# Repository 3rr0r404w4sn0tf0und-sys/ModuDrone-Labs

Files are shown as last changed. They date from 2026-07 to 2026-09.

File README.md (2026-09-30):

# ModuDrone Labs v1

An open-source, heavy-lift agricultural octocopter designed to challenge closed, proprietary drone ecosystems. ModuDrone Labs v1 is a student-led, 4-year engineering initiative focused on building a modular, repairable, and high-performance industrial flight platform using off-the-shelf hardware and custom fabrication.

## 🚀 Quick Links
* **CAD**  :  [Onshape CAD](https://cad.onshape.com/documents/e87d46874a385fbec040f01c/w/3f5500552e76a844099c1e4a/e/fdc0c3d3f0b3d21b94bce90c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)
* **ODOO** :  [https://modudrone-labs.odoo.com/](https://modudrone-labs.odoo.com/) 
---

## 📐 Platform Specifications

* **Frame Configuration**: Industrial Co-Axial Octocopter (4-Arm design with 3K Carbon Fiber tubes)
* **Propulsion Stack**: MAD Components M7C15 IPE motors spinning 27.2*8.9" MAD Fluxer Props
* **Communications Protocol**: Integrated DroneCAN architecture for robust electronic reliability
* **Primary Flight Controller**: Pixhawk 6x with triple redundancy and mroe ports for expansion
* **Companion Intelligence**: Jetson Orin Nano Developer Kit for localized AI perception and processing
* **Sensor Payload**: YDLIDAR G4, TFmini-Plus altimeter, and SIYI ZR30 Gimbal Camera
* **RTK GPS**: H-RTK mosaic-H (Dual Antenna Heading)
* **Power Plant**: 2 Foxtech 12S 36000mAh Batterys running through a MAUCH PDB

---

## 🛠 Project Lifecycle & Current Status

This is a long-term **4-year project** focused on absolute engineering transparency. 

* **Phase 1: Conceptual Architecture & CAD Modeling** ------------------------------------------ 🔵 *[COMPLETED]*
  * Finalizing the aerodynamic central fuselage hull shell within Onshape.
  * Structural layout optimization for the 8-arm carbon fiber chassis leverage points.




* **Phase 2: R&D Prototyping & Design** -------------------------------------------------------- 🟢 *[CURRENT PHASE]*
  * Wind Tunnel Testing
  * AIRsim testing
  * Extra Reinforcements and CAD check period.
* **Phase 3: Funding** ------------------------------------------------------------------------- 🟡
  * Grant proposals and applications
* **Phase 4: Flight Integration & Testing** ---------------------------------------------------- 🔴
  * 3d print the frame and build it.
  * Core autopilot parameter tuning and testing sensory loop feedback (LiDAR / Gimbal).
* **Phase 5: Part 47, 44807, manual, and legal draft - Funding Period 2** ---------------------- 🔴
  * Hire Lawyer to write legal contracts, and forms to acquire the part 47 heavy lift exemption.
  * Write the User Manual
  * Make 44807 template
  * RTL testing, and Failsafe Testing.
* **Phase 6: Open Commercialization** ---------------------------------------------------------- 🔴
  * Launching open-source kit architectures for independent distribution.

---

## 📜 Licensing & The Anti-Proprietary Shield

We believe hardware ecosystems should be accessible and owned by the community, not locked down by restrictive corporations. To guarantee this project remains permanently open, it is protected under a strict copyleft shield:

* **Software & Configurations**: This repository's code, scripts, and flight configuration files are initially licensed under the **GNU Affero General Public License v3 (AGPLv3)**. 
* **Hardware & Geometry**: *All physical CAD models, STEP files, and frame geometries are governed by the [CERN Open Hardware Licence v2 - Strongly Reciprocal (CERN-OHL-S-2.0)](./CAD/HARDWARE_LICENSE.md)*

**The Copyleft Guarantee**: Anyone is legally allowed to modify, adapt, or build upon this architecture. However, any derivative modifications or improvements **must be published openly under these exact same terms**. If you optimize our layout, your improvements must legally remain free for the public—and us—to utilize.
- 💻 **Software & Configurations:** Licensed under [GNU AGPLv3](LICENSE) — `SPDX-License-Identifier: AGPL-3.0-only`
- 🔩 **Hardware & Geometry:** Licensed under [CERN-OHL-S-2.0](CAD/HARDWARE_LICENSE.md) — `SPDX-License-Identifier: CERN-OHL-S-2.0`

---

## 👥 Core Engineering Team
Developed with passion by a student-led engineering collective. 
* **Contact**: ModuDroneTeam@hotmail.com

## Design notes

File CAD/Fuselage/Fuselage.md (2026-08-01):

# 🛩️ **Fuselage CAD Directory**
This folder contains all CAD models, assemblies, and reference geometry for the **ModuDrone main fuselage**.  
It serves as the central workspace for the structural body that houses the drone’s internal systems.

---

## 📦 **What Lives Here**
- Full fuselage **solid models**  



---

## 🧱 **Design Intent**
The fuselage is engineered to:
- Provide a rigid central structure for the Co-Axial layout  
- Support high‑torque MAD motor loads through reinforced clamp nodes  
- Maximize internal usable volume while minimizing mass  
- Maintain clean airflow paths for cooling and sensor visibility  
- Serve as the anchor for all modular subsystems in the ModuDrone platform

---

## 🔄 **Update Workflow**
All fuselage changes should follow the standard ModuDrone workflow:
1. Edit or add CAD in Onshape  
2. Export STEP files  
3. Commit to this directory with a clear message  
4. Add notes to `Updates.md` if the change affects assembly geometry or subsystem integration

---

## 📘 **Notes**
This folder is actively evolving as the fuselage transitions from a visual prototype to a weight‑optimized flight‑ready structure.  
Expect frequent updates as internal hollowing, mounting revisions, and structural optimizations progress.

V2 is missing as it was just pure sketches.

---

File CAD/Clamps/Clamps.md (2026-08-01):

# 🔩 **Clamp CAD Directory**
This folder contains all CAD models, assemblies, and reference geometry for the **ModuDrone clamping systems**, including both **motor‑mount clamps** and **arm clamps**.  
These components mechanically secure the propulsion system and structural arms to the fuselage.

---

## 🧱 **What’s Inside**
### **Motor‑Mount Clamps**
- 30 mm carbon‑fiber tube clamp bodies  
- PA612‑CF printable variants  
- M6 heat‑set insert bosses (7–8 mm reinforced)  
- Through‑pin channel geometry for torque‑locking  
- Mounting interfaces for MAD HAVOC motor plates

(With Simplified Motors)

---

## 🛠️ **Design Intent**
The clamp subsystem is engineered to:
- Provide rigid, slip‑free attachment of arms and motor tubes  
- Withstand high‑torque loads from large‑format MAD motors  
- Maintain precise thrust‑vector alignment across the V‑Octo layout  
- Support PA612‑CF manufacturing constraints (wall thickness, boss geometry, print orientation)  
- Allow modular replacement and rapid iteration during prototyping

---

## 🔄 **Update Workflow**
1. Modify or create clamp geometry in Onshape  
2. Export STEP files  
3. Commit changes with clear version notes  
4. Add relevant updates to `Updates.md` if clamp geometry affects fuselage, motor spacing, or assembly alignment

---

## 📘 **Notes**
This directory evolves alongside the fuselage and propulsion system.  
Expect frequent updates as clamp strength, weight, and manufacturability are optimized for PA612‑CF printing and high‑thrust MAD motor operation.

---

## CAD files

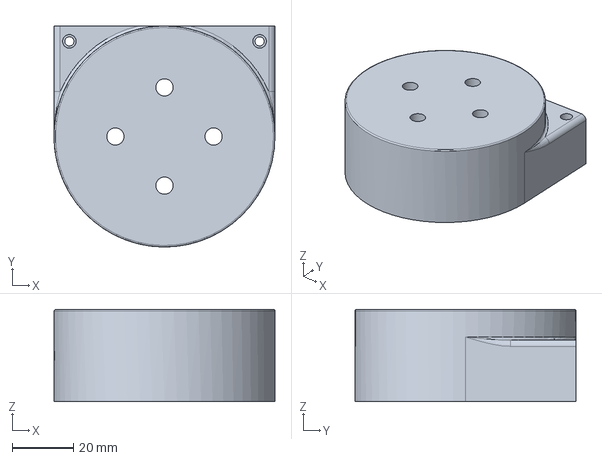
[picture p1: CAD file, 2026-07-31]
CAD/Clamps/Main motor mount V4-Top.step
72.0 x 72.0 x 30.0 mm

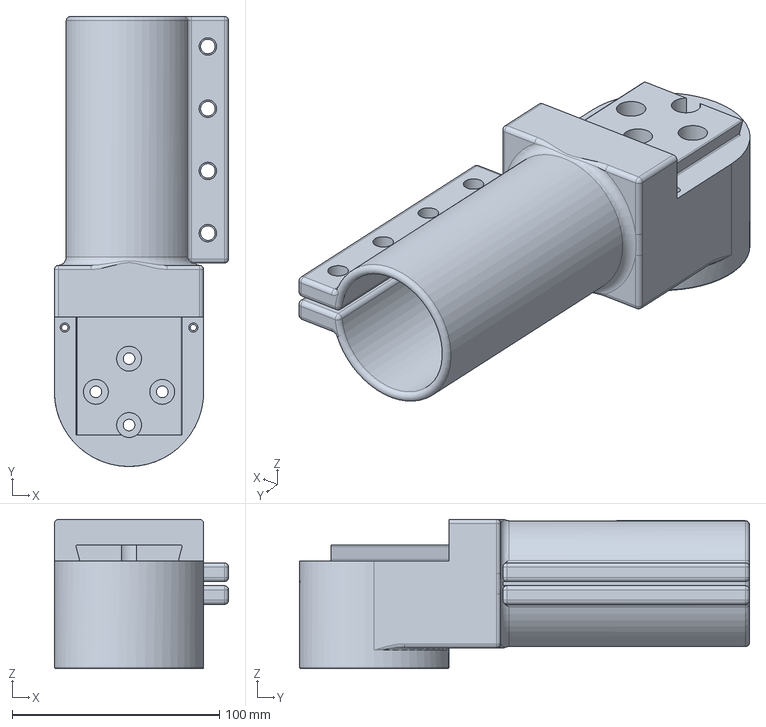
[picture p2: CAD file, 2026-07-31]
CAD/Clamps/Motor/Main motor mount V4-Bottom.step
84.0 x 217.0 x 72.0 mm

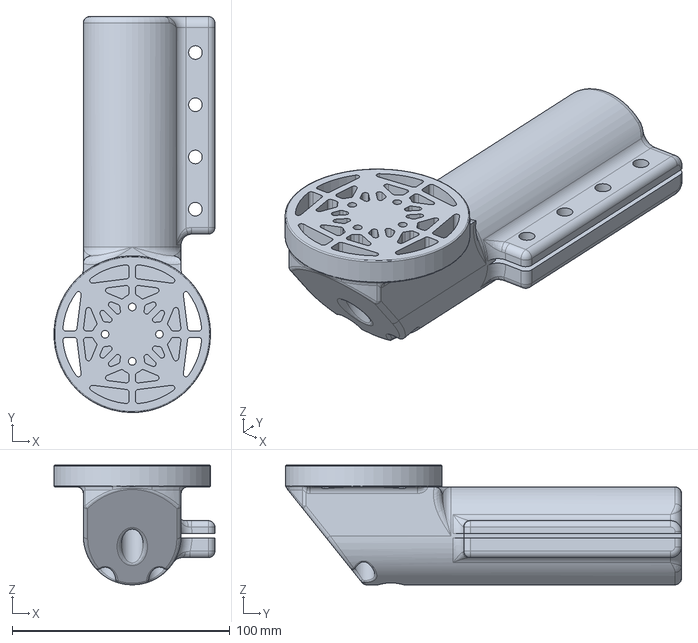
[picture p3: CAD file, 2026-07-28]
CAD/Clamps/Main motor mount V2.step
73.9 x 182.0 x 55.0 mm

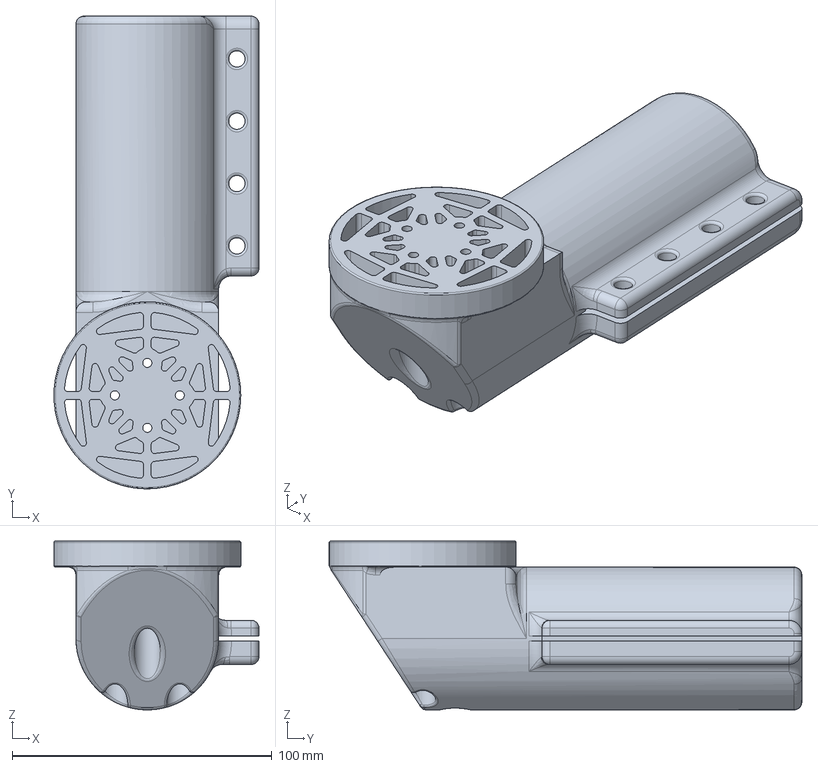
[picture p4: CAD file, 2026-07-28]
CAD/Clamps/Motor/Main motor mount V3.step
78.9 x 182.0 x 65.0 mm

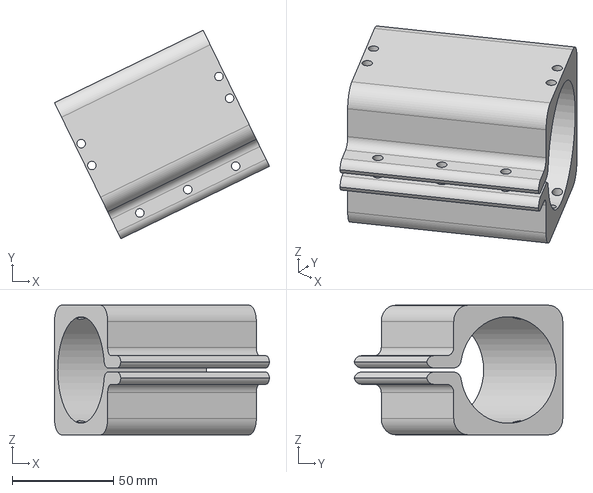
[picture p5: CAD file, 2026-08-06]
CAD/Clamps/ESC/Fuselage Design v6 - ESC Clamp Back.step
106.3 x 103.2 x 64.1 mm

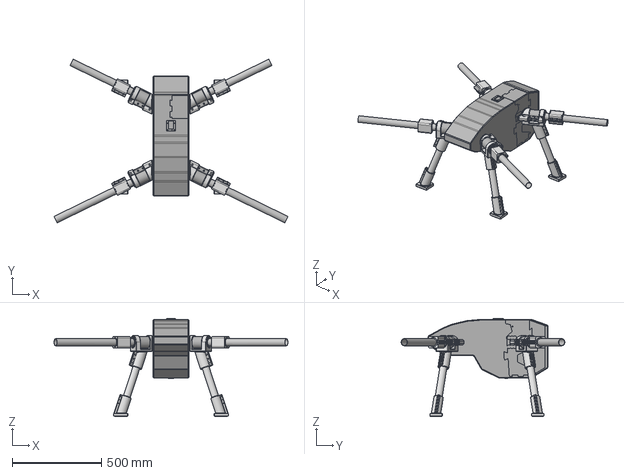
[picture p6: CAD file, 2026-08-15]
CAD/Fuselage/Fuselage Design v7 - Static.step
1312.2 x 918.1 x 550.8 mm

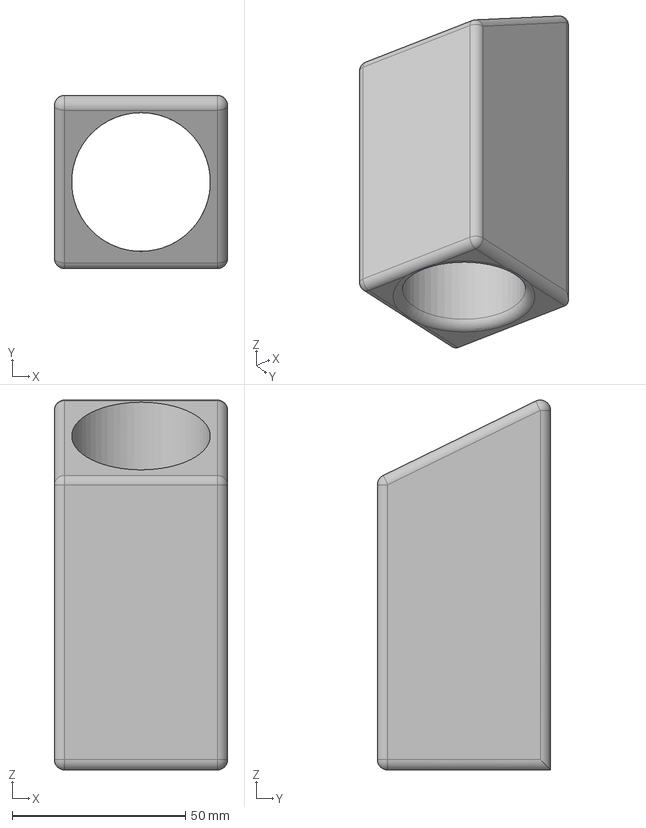
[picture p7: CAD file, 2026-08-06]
CAD/Guides/Arm Cut Guide.step
50.0 x 50.0 x 106.7 mm

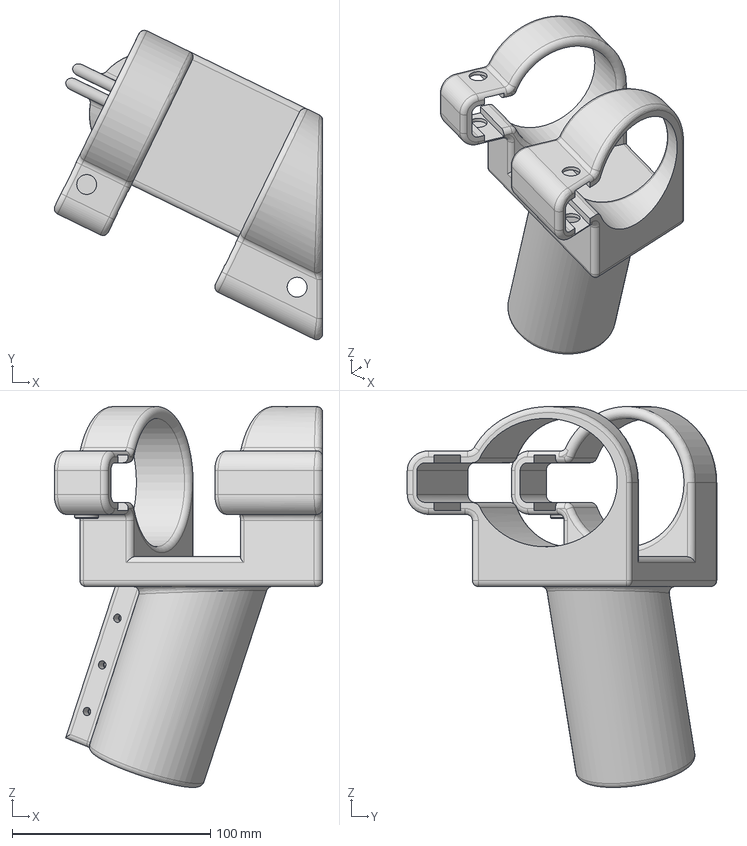
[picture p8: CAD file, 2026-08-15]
CAD/Landing Gear/Clamps/Landing Gear Mount Back Right.step
135.3 x 156.0 x 192.0 mm

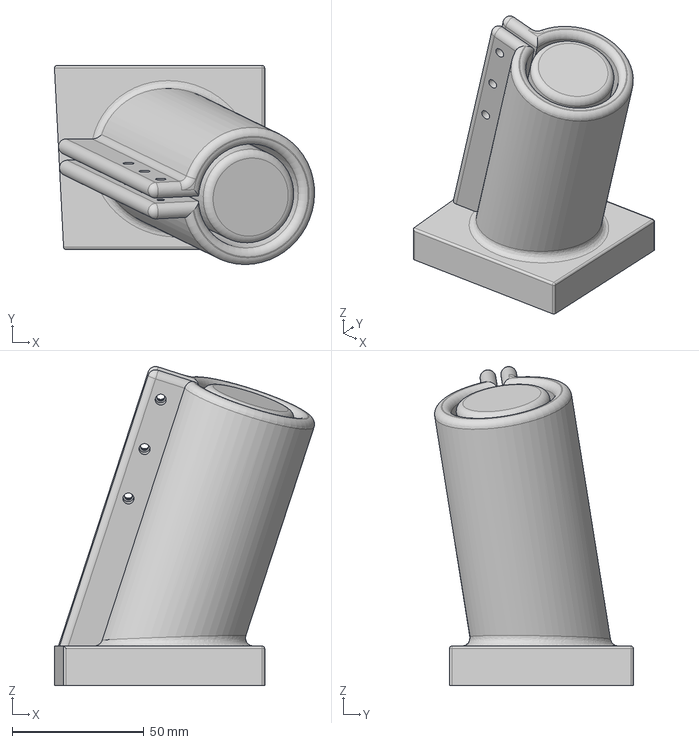
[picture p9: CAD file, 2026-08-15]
CAD/Landing Gear/Feet/Foot 4.step
98.9 x 75.7 x 121.3 mm

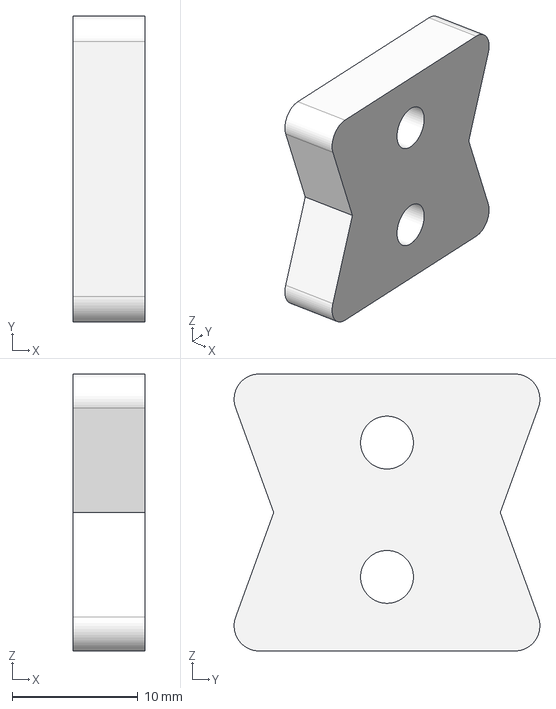
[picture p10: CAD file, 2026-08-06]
CAD/Printed Locking Plates/Printed Back Locking Plate 2x.step
5.70 x 24.3 x 22.0 mm

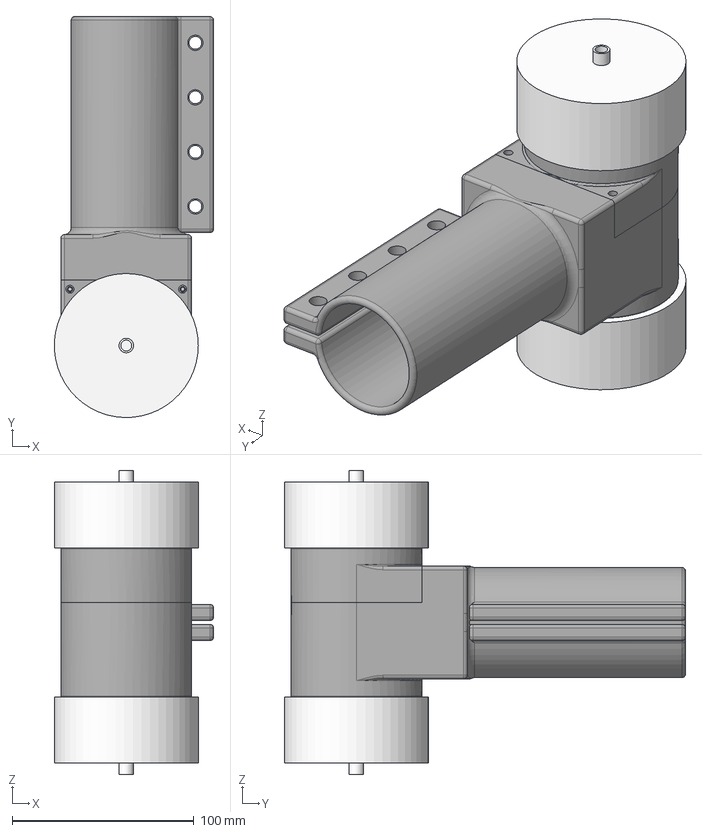
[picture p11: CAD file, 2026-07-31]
CAD/Clamps/Motor/Motor Mount Static.step
87.5 x 220.6 x 167.4 mm
M4 10mm Button Head v1:1__Body1 x 8
Clamp V4 Top
Simp Model x 2
Clamp V4 Bottom
M3 30mm Button Head v1:1__Body1 x 2

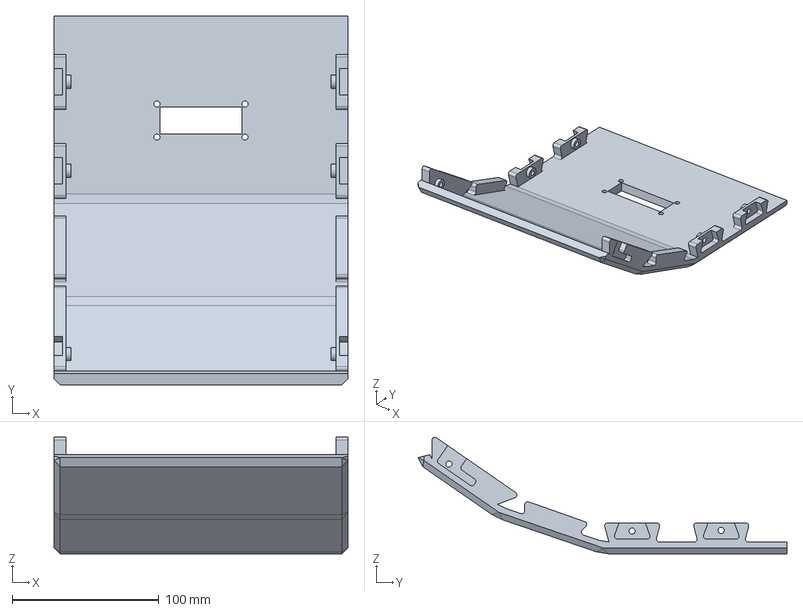
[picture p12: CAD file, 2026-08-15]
CAD/Fuselage/Fuselage Design v7 - Front Bottom.step
200.0 x 251.4 x 79.4 mm

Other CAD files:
CAD/Clamps/ESC/Fuselage Design v6 - ESC Clamp Front.step
CAD/Landing Gear/Clamps/Landing Gear Mount Front Left.step
CAD/Landing Gear/Feet/Foot 3.step
CAD/Printed Locking Plates/Printed Middle Locking Plate 2x.step
CAD/Clamps/Archive/Motor mount V1.step
CAD/Clamps/Main motor mount V1.step
CAD/Fuselage/Archive/Fuselage Design v1.step
CAD/Fuselage/Archive/Fuselage Design v3.step
CAD/Fuselage/Archive/Fuselage Design v4-Arms.step
CAD/Fuselage/Archive/Fuselage Design v4-No Arms.step
CAD/Fuselage/Archive/Fuselage Design v6 - Back Bottom.step
CAD/Fuselage/Archive/Fuselage Design v6 - Back Top.step
CAD/Fuselage/Archive/Fuselage Design v6 - Front Bottom.step
CAD/Fuselage/Archive/Fuselage Design v6 - Front L.step
CAD/Fuselage/Archive/Fuselage Design v6 - Front R.step
CAD/Fuselage/Archive/Fuselage Design v6 - Middle Bottom.step
CAD/Fuselage/Archive/Fuselage Design v6 - Middle Left 1.step
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

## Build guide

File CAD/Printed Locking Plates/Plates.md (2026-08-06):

# Printed Locking Plates
This folder contains all 3D‑printed locking plates used in the ModuDrone v1 fuselage and module system.

These plates are specifically for **tight or constrained areas** where standard T‑brackets, steel plates, or larger structural connectors cannot fit.  
They provide lightweight reinforcement, alignment, and clamping for small interfaces throughout the drone.



## Included in this folder
- Small locking plates for rib interfaces  
- Clamp plates for sockets and mounts  
- Thin reinforcement plates for narrow structural gaps  
- Cover plates for wiring channels or tight access points  
- Any plate designed to “lock” two parts together where a T‑bracket is too large

## Notes
- All plates in this folder are designed for **3D printing only**  
- Typical print settings: 3 walls, 25–40% gyroid, CF‑Nylon  
- Fasteners vary (M3–M6) depending on the plate’s location  
- These plates are used throughout the fuselage, front module, and rear module

## Purpose of this folder
To keep all **small-format structural locking plates** organized in one place, separate from other parts

This ensures the CAD directory stays clean and modular as the V6 fuselage expands.

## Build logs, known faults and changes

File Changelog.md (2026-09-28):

## 🛠️ Engineering Update — FC, GPS, and controllers change.
**📅 2026‑09‑28 • 06:26 EDT**

### Summary of Major Revisions
- **Fuselage:** V6 Rev6 → **V7**
- **Motor Clamp:** V4 (unchanged)  
- **Arm Clamp:** V1 (unchanged)  
- **ESC Clamp:** V1 (unchanged)  
---

### 🔧 Major Milestones
- New FC change and RTK GPS change
- Battery bay change
- Controller change
---

### 📐 Structural Improvements
- Battery bay changed back and moved to the center for better COG/COM
---
### Changes
- Controllers changed from T16000m HOSAS to HOSAS Gladiator NXT evo controllers
- Faster lower latency in theory controls
- Direct from Pi 02w to HM30 Ground Unit
---
### 📦 BOM Updates
- Major FC and GPS change
- Changed FC from Cube Orange to Pixhawk 6x
- Changed GPS from cheap m10 GPS to H-RTK Mosaic-H dual antenna GPS

---

### 🧩 Next Steps
- AIR sim Testing.     

---
## 🛠️ Engineering Update — Fuselage **V7 Release**
**📅 2026‑08‑18 • 10:52 EDT**

### Summary of Major Revisions
- **Fuselage:** V6 Rev6 → **V7**
- **Motor Clamp:** V4 (unchanged)  
- **Arm Clamp:** V1 (unchanged)  
- **ESC Clamp:** V1 (unchanged)  
---

### 🔧 Major Milestones
- Entered **Fuselage V7**, a refinement‑focused update aimed at precision, CG stability, and control‑system responsiveness.  
- Completed a **full battery bay redesign** to achieve perfectly centered mass alignment:  
  - CG offset now **<5 mm** on all lateral axes(Y axis should balance out once wiring is added)  
  - Balanced cable routing to maintain equal electrical path lengths  
- Began **experimental low‑latency control system Researching** using:  
  - **Gladiator NXT EVO sticks**  
  - **Direct UART injection** into the flight controller  

---
<table>
<tr>
<td></td>
<td></td>
<td></td>
</tr>
</table>

### 📐 Structural Improvements
- Battery bay geometry updated for centered dual‑pack seating:  
  - Re‑profiled lower fuselage curvature  
  - Adjusted rib cutouts for symmetric load distribution  
  - Cleaned internal routing channels for parallel 12S pack leads  
- No major changes to landing gear, fuselage ribs, or carbon‑rod bracing beyond minor alignment tweaks required by the new battery bay.

---

### 📦 BOM Updates
- No major BOM changes for V7.  
- Battery‑related connectors and cable lengths remain identical to V6 Rev6.

---

### 🧩 Next Steps
- Gazebo Testing.  
- Continue latency‑reduction researching.   

---
## 🛠️ Engineering Update — Landing Gear & Capacity Expansion  
**📅 2026‑08‑10 • 00:55 EDT**
### Summary of Major Revisions
- **Fuselage:** V6 → **V6 Rev6**  
- **Motor Clamp:** V4 (unchanged)  
- **Arm Clamp:** V1 (unchanged)  
- **ESC Clamp:** V1 (unchanged)  
- **New Additions:**
    - Landing Gear System V1(Initial Launch)
    - Expanded Dual‑Battery Bay (72 Ah 12S)
---
<details>
<summary>📷 image</summary>


</details>

### 🔧 Major Milestones
- Entered **Fuselage V6 Rev6**, marking the shift toward flight‑ready geometry and subsystem integration.  
- Added a full **landing gear assembly** designed for agricultural UAV operations:  
  - Wide‑stance geometry for stable ground handling  
  - Reinforced mounting plates tied directly into fuselage ribs  
  - Carbon‑rod cross‑members to prevent flex during touchdown  
- Completed expansion of the **battery bay** to support **dual 36 Ah 12S packs in parallel**, enabling:  
  - **Total capacity:** 72 Ah  
  - **Effective discharge:** 20C (2× 10C packs)  
  - Substantially increased endurance for heavy‑lift and long‑route spraying missions  
- Updated internal rib spacing and carbon‑rod bracing to maintain torsional rigidity despite the larger battery footprint.
<table>
<tr>
<td></td>
<td></td>
<td></td>
</tr>
</table>
---

### 📐 Structural Improvements
- Battery bay enlargement required adjustments to:  
  - Lower fuselage curvature  
  - Rib cutouts and reinforcement patterns  
  - High‑current cable routing channels for parallel pack leads  
- Landing gear integration introduced:  
  - New load‑bearing sockets bonded to the fuselage spine  
  - Shock‑resistant geometry to reduce vibration transfer into avionics  
- Overall benefits:  
  - Improved CG alignment with dual‑pack configuration  
  - More predictable load paths during landing/takeoff  
  - Cleaner separation between battery bay, ESC corridor, and avionics shelf
---

### 📦 BOM Updates
- Added:  
  - Second Battery  
  - Second AS150u to QS8-S adapter
  - More QS8-S Ports 
- Revised:  
  - PC1500 to PC2500

---

### 🧩 Next Steps
- Validate landing gear under simulated touchdown loads  
- Begin endurance‑focused airflow and cooling analysis for dual‑pack configuration
- Simulate in Gazebo
- Simulate in UE5

---
## 🛠️ Engineering Update — Fuselage V6 Progress & Structural Additions
**📅 2026‑08‑05 • 23:05 EDT**
### Summary of Major Revisions
- Fuselage: V5 → V6
- Motor Clamp: V3 → V4
- Arm Clamp: V1
- ESC Clamp: V1(Initial Release)
---

### 🔧 Major Milestones
- Officially entered **Fuselage V6**

- Made ESC mounts

- Completed **full sectioning of the fuselage**, establishing clear boundaries for:
  - Front module
  - Mid‑section core  
  - Rear module  
- Added new **carbon‑rod reinforcements** to the BOM to increase torsional rigidity and reduce printed‑part load.
  - Includes additional 10x8(OD, ID)mm rods for Internal Ribs  
  - Updated BOM with parts mentioned above, and new filament

---

### 📐 Structural Improvements
- Sectioning the fuselage allowed proper isolation of:
  - Battery bay  
  - ESC cooling corridor  
  - Sensor nose compartment  
  - Rear avionics shelf  
- This segmentation ensures cleaner assembly, easier maintenance, and more predictable load paths.
- Carbon‑rod additions significantly improve stiffness across the fuselage spine and arm sockets.

---

### 🔩 New Component: ESC Clamp (V1)
- Designed and finalized a **new ESC clamp** specifically for the rear module.
- Purpose:
  - Secure ESCs against vibration
  - Mount ESCs Securely

---

### 📦 BOM Updates
- Added:
  - Additional carbon rods (structural + internal bracing)  
  - ESC clamp (printed)  
  - Updated fastener counts for rear module  
- Revised:
  - Fuselage V6 part grouping  
  - Printed plate folder structure  
  - Locking plate documentation

---

### 🧩 Next Steps
  - Wind Tunnel Testing
  - Model Dummy Electronics
  - Model Camera Mounting Holes

---

## 🛠️ Engineering Update — Front Fuselage Split (Work in Progress)
**📅 2026‑08‑04 • 22:31 EDT**

---

### 🔧 Current Progress
- Continued splitting the **front fuselage module** into multiple printable sections. The geometry is still being refined, but the main separation planes are established and behaving well.
- Started transitioning from a single large dovetail to **multiple smaller dovetails** along the curved seam. This is already improving alignment and reducing binding during test fits.
- Applied fillets to new edges created by the split. This helps reduce stress concentrations and makes the PA612‑CF geometry print cleaner.
- Continued shaping the **camera‑mount lower housing**. Even though it doesn’t tie into the carbon‑rod frame, internal ribs and supports are being added so it still contributes to front‑section stiffness.




---

### 🚧 Still in Progress
- Finalizing the **battery pack holder** geometry. This will be integrated into the split fuselage once the front section is fully stabilized.
- Additional fillets and internal supports will be added once the battery bay layout is locked in.
- More adjustments expected as the front and bottom sections are test‑printed and checked for fit after funding.

---

## 🛠️ **Engineering Update — Arm Clamp Completion & Fuselage V5 Integration**
**📅 2026‑08‑01 • 12:22 EDT**
### Summary of Major Revisions
- Fuselage: V4 → V5
- Motor Clamp: V3 → V4
- Arm Clamp: V1 (initial release)
---

### 🔧 **Milestone Completed**
- Completed the full CAD for the **V5 arm‑clamp system**, including the revised 40 mm bore, 4 mm structural fillets, and updated geometry for carbon‑rod integration.
- Finalized the **V5 fuselage architecture**, incorporating the new clamp interface, updated arm spacing, and improved structural continuity across the central frame.
- Validated the clamp‑to‑arm transition clearances, ensuring proper fitment for **40×36 mm carbon rods** and eliminating interference caused by earlier oversized fillet radii.



---

### 📐 **Geometric Validation & Structural Improvements**
- Confirmed that the clamp geometry maintains correct alignment with the fuselage’s arm sockets, preserving structural load paths and minimizing stress concentrations at the 40 mm bore.
- Ensured that the 4 mm fillet radius provides adequate reinforcement without interfering with arm geometry or reducing wall thickness around the clamp interface.
- Verified fuselage V5 symmetry, arm spacing, and motor‑mount alignment for the coaxial propulsion layout.
- Updated CAD assemblies to reflect accurate mass properties for clamps, arms, motors, and props prior to infill adjustments.
- Calculated the full V5 assembly mass at **87.2009637 lb (≈39.55 kg)** before hollowing, infill slicing, or internal structural reduction.

---

### 🧩 **Next Steps**
- Begin **internal hollowing** of the fuselage V5 shell to prepare for 30% gyroid infill slicing with 4 walls and 4 floors/roofs.
- Recalculate mass properties after infill reduction to establish accurate flight‑ready weight estimates.
- Integrate **ESC mounting geometry**, wiring channels, and power‑distribution pathways into the fuselage interior.

---

## 🛠️ **Engineering Update — Powertrain & Architecture Overhaul**
**📅 2026‑07‑30 • 22:59 EDT**

---

### 🔧 **Milestone Completed**
- Migrated the propulsion system to **MAD M7C15 IPE motors**, providing higher torque density, improved thermal stability, and IP45‑rated environmental protection suitable for manned‑class reliability.
- Upgraded to a **higher‑current ESC platform**, enabling cleaner transient response, reduced voltage sag, and improved sustained‑thrust performance under heavy load.
- Integrated the **Cube Orange+** flight controller, adding triple‑redundant IMUs, advanced vibration isolation, and expanded sensor‑fusion capabilities for precision flight and safety.
- Converted the airframe to a **coaxial propulsion layout**, increasing total thrust output while reducing arm span and improving yaw authority.
- Updated the master geometry to support **27.2 × 8.9″ propellers**, validating rotor‑disk clearance, coaxial spacing, and aerodynamic interaction between upper and lower rotors.



(Exploded)

---

### 📐 **Geometric Validation & Structural Improvements**
- Verified that the larger **M7C15 motor housings** fit cleanly within the revised mount architecture, maintaining correct bolt‑circle alignment and ensuring no interference with adjacent structural components.
- Confirmed coaxial spacing meets aerodynamic requirements for:
  - minimized rotor‑wash interference  
  - stable thrust symmetry across the full throttle range  
  - reduced vibration coupling into the flight‑controller bay  
- Validated ESC placement and airflow paths to ensure adequate cooling during peak current draw.
- Updated CAD assemblies to reflect the new motor geometry, ESC footprint, and coaxial stack height, ensuring compatibility with the existing frame and clamp system.

---

### 🧩 **Next Steps**
- Design the **new ESC mounting plate** with improved airflow and vibration isolation.  
- Update the **motor‑clamp reinforcement** to match the increased torque output of the M7C15 motors.  

---

## 🛠️ **Engineering Update — Motor Clamp Wall Reinforcement**
**📅 2026‑07‑28 • 20:36 EDT**

---

### 🔧 **Milestone Completed**
- Increased the **motor‑clamp outer diameter to 55 mm** while maintaining the required **42.7 mm inner diameter** for the 30 mm CF tube + rubber liner stack.
- Achieved a reinforced **6.15 mm wall thickness** (up from 3.65 mm), significantly improving clamp rigidity, torque‑load tolerance, and long‑term structural durability.
- Updated the clamp geometry in the Onshape assembly to ensure seamless integration with the existing motor‑mount layout.


---

### 📐 **Geometric Validation & Structural Improvements**
- Verified that the new **55 mm OD** maintains full clearance within the motor‑mount region and does not interfere with adjacent arm geometry.
- Confirmed **6.15 mm wall thickness** meets PA612‑CF print requirements for:
  - torsional resistance under high‑output MAD motors  
  - uniform compression around the 30 mm tube  
  - reduced deformation under sustained thrust loads  
- Revalidated clamp alignment relative to the global horizontal plane to preserve consistent thrust‑vector orientation across all motor positions.

---

### 🧩 **Next Steps**
- Begin hollowing the fuselage interior and define electronics‑bay geometry.
- Add additional clamp variants and determine fuselage split‑line strategy.
- Integrate **arm‑clamp** geometry and validate fit against the updated motor‑clamp dimensions.

---

## 🛠️ **Engineering Update — Motor Mount Integration & Geometry Validation**
**📅 2026‑07‑27 • 22:17 EDT**

---

### 🔧 **Milestone Completed**
- Integrated the **30 mm carbon‑fiber tube motor‑mount clamps** directly into the main Onshape assembly.
- Ensured all mounts sit **perfectly parallel to the global horizontal plane**, guaranteeing uniform downward thrust vectors across the asymmetric V‑Octo layout.

---

### 📐 **Geometric Validation & Layout Specs**
- Verified structural clearance for the **22" (560 mm) MAD HAVOC propellers** using master layout sketches.
- Confirmed pre‑rotor frame wingspan: **≈ 1848.58 mm**.
- Validated asymmetric V‑Octo spacing:
  - Adjacent motor centers maintain a **≥ 110 mm (4.3") rotor‑tip clearance**.
  - Provides safe margin for **blade flex**, **dynamic deflection**, and **manufacturing tolerances**.

---

### 🧩 **Next Steps**
- Hollow out the interior of the fuselage and model where electronics go.
- Add additional clamps, and figure out how to split.
- Add arm clamps.
  
---

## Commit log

2026-07-28 Moved Clamp v1 to archive
    Older, Outdated model.
    [Main motor mount V1.step]
2026-07-28 Moved Clamp v2 To Archive
    Moved due to insufficient walls and misdone dimensions.
    [Main motor mount V2.step]
2026-07-28 Moved Fuselage design ref v1 to Archive
    Previous idea to use aluminum arms instead of CF-Rods, Outdated.
    [Fuselage Design Reference.step]
2026-07-28 Moved V1 to Archive
    Previous Idea to use aluminum arms, TOO HEAVY, Outdated.
    [Fuselage Design Reference.step]
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2026-07-28 Rename CAD/Archive/Clamp Archive/Main motor mount V1.step to CAD/Archive/Clamp Archive/Motor Clamp/Main motor mount V1.step
    [Main motor mount V1.step]
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2026-07-28 Moved To Archive
    Moved due to insufficient wall perimeter.
    [Main motor mount V2.step]
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2026-07-28 Organization
    Same as earlier, thicker walls, just organizing
    [Main motor mount V3.step]
2026-07-28 Moved to Archive
    Walls too small
    [Main motor mount V2.step]
2026-07-29 Moved to Archive
    Aluminum arms variant, too heavy, outdated
    [Fuselage Design v1.step]
2026-07-30 Moved to Archive
    I realized the m6c12 wouldnt do for heavy lift, and decided for m7c15 and non coaxial wouldnt let me use 27" props so complete redesign!
    [Fuselage Design v3.step]
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2026-07-30 Moved to Archive
    Not big enough for 40mm rods, no angling
    [Main motor mount V3.step]
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2026-08-06 All the Sections Needed
    Took me a couple days but i sectioned it off, length was increased slightly by 12mm
    [Fuselage Design v6 - Back Bottom.step, Fuselage Design v6 - Back Top.step, Fuselage Design v6 - Front Bottom.step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]
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2026-08-07 Rename Fuselage Design v6 - Middle Bottom (1).step to Fuselage Design v6 - Middle Bottom.step
    [Fuselage Design v6 - Middle Bottom.step]
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2026-08-15 feat: upload Landing Gear Mount Back Right.step from Onshape
    [Landing Gear Mount Back Right.step]
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2026-08-15 chore: archive previous Landing Gear Mount Back Right.step
    [Landing Gear Mount Back Right.step]
2026-08-15 chore: remove old Landing Gear Mount Back Right.step (archived)
    [Landing Gear Mount Back Right.step]
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2026-08-15 feat: upload Landing Gear Mount Front Right.step from Onshape
    [Landing Gear Mount Front Right.step]
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2026-08-15 feat: upload Landing Gear Mount Front Left.step from Onshape
    [Landing Gear Mount Front Left.step]
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2026-08-15 chore: archive previous Fuselage Design v6 - Back Top.step
    [Fuselage Design v6 - Back Top.step]
2026-08-15 chore: remove old Fuselage Design v6 - Back Top.step (archived)
    [Fuselage Design v6 - Back Top.step]
2026-08-15 feat: upload Fuselage Design v7 - Back Top.step from Onshape
    [Fuselage Design v7 - Back Top.step]
2026-08-15 chore: archive previous Fuselage Design v6 - Back Bottom.step
    [Fuselage Design v6 - Back Bottom.step]
2026-08-15 chore: remove old Fuselage Design v6 - Back Bottom.step (archived)
    [Fuselage Design v6 - Back Bottom.step]
2026-08-15 feat: upload Fuselage Design v7 - Back Bottom.step from Onshape
    [Fuselage Design v7 - Back Bottom.step]
2026-08-15 chore: archive previous Fuselage Design v6 - Middle Right 1.step
    [Fuselage Design v6 - Middle Right 1.step]
2026-08-15 chore: remove old Fuselage Design v6 - Middle Right 1.step (archived)
    [Fuselage Design v6 - Middle Right 1.step]
2026-08-15 feat: upload Fuselage Design v7 - Middle R1.step from Onshape
    [Fuselage Design v7 - Middle R1.step]
2026-08-15 chore: archive previous Fuselage Design v6 - Middle Right 2.step
    [Fuselage Design v6 - Middle Right 2.step]
2026-08-15 chore: remove old Fuselage Design v6 - Middle Right 2.step (archived)
    [Fuselage Design v6 - Middle Right 2.step]
2026-08-15 feat: upload Fuselage Design v7 - Middle R2.step from Onshape
    [Fuselage Design v7 - Middle R2.step]
2026-08-15 chore: archive previous Fuselage Design v6 - Middle Bottom.step
    [Fuselage Design v6 - Middle Bottom.step]
2026-08-15 chore: remove old Fuselage Design v6 - Middle Bottom.step (archived)
    [Fuselage Design v6 - Middle Bottom.step]
2026-08-15 feat: upload Fuselage Design v7 - Middle Bottom.step from Onshape
    [Fuselage Design v7 - Middle Bottom.step]
2026-08-15 chore: archive previous Fuselage Design v6 - Middle Left 1.step
    [Fuselage Design v6 - Middle Left 1.step]
2026-08-15 chore: remove old Fuselage Design v6 - Middle Left 1.step (archived)
    [Fuselage Design v6 - Middle Left 1.step]
2026-08-15 feat: upload Fuselage Design v7 - Middle L1.step from Onshape
    [Fuselage Design v7 - Middle L1.step]
2026-08-15 chore: archive previous Fuselage Design v6 - Middle Left 2.step
    [Fuselage Design v6 - Middle Left 2.step]
2026-08-15 chore: remove old Fuselage Design v6 - Middle Left 2.step (archived)
    [Fuselage Design v6 - Middle Left 2.step]
2026-08-15 feat: upload Fuselage Design v7 - Middle L2.step from Onshape
    [Fuselage Design v7 - Middle L2.step]
2026-08-15 chore: archive previous Fuselage Design v6 - Front R.step
    [Fuselage Design v6 - Front R.step]
2026-08-15 chore: remove old Fuselage Design v6 - Front R.step (archived)
    [Fuselage Design v6 - Front R.step]
2026-08-15 feat: upload Fuselage Design v7 - Front R.step from Onshape
    [Fuselage Design v7 - Front R.step]
2026-08-15 chore: archive previous Fuselage Design v6 - Front L.step
    [Fuselage Design v6 - Front L.step]
2026-08-15 chore: remove old Fuselage Design v6 - Front L.step (archived)
    [Fuselage Design v6 - Front L.step]
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2026-08-15 chore: delete Fuselage Design v6 - Static.step (replaced)
    [Fuselage Design v6 - Static.step]
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
